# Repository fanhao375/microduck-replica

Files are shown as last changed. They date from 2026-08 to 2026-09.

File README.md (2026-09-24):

# Microduck 复刻

**简体中文** · [English](README.en.md)

> 对 [Pollen Robotics Microduck](https://pollen-robotics.com/microduck/) 的第三方复刻研究。
> 从官方公开的 MJCF 仿真模型反推出**装配图、爆炸图和可直接导入 CAD 的装配体**。

Microduck 是一只 25cm 高、737g 的双足机器鸭，15 个 Dynamixel XL330 舵机（14 个受策略控制），用强化学习走路。
它的**软件开源（Apache-2.0）**。硬件是**部分开源**：

- ✅ **RPI Robot HAT 板完整开源** —— 见 [`pollen-robotics/elec_RPI_Robot_HAT`](https://github.com/pollen-robotics/elec_RPI_Robot_HAT)（Apache-2.0）：
  KiCad 9 工程、Gerber、BOM、贴片坐标、STEP 一应俱全。这块板**不需要自己画**。
- ❌ **`imu_to_dxl` 板未开源** —— 全网无公开工程，本仓库的逆向是目前唯一公开重建。
- ❌ **机械件无可编辑 CAD**、无 BOM、无装配文档。

> 📌 **勘误（2026-09-03）**：本文档此前写作「硬件不开源、没有 PCB 原理图」，**这是错的**。
> 当时只检索了 `pollen-robotics/microduck` 主仓，未翻查该组织下以 `elec_` 开头的硬件仓库。

但官方在 `microduck_rl` 里发布了完整的 **MJCF 仿真模型 + 47 个 STL 网格**。
MJCF 里包含了完整的运动学树：每个零件挂在谁身上、相对位置精确到 0.1mm、
绕哪根轴转、行程多少、质量和惯量张量。

**这些信息足以还原出装配关系。** 本仓库就是把它还原出来的结果。

---

## 两条路线，选一条走

本仓库同时覆盖两种舵机。**机械、电路、软件三层都有差别**，动手前先定：

| | 原版 · Dynamixel XL330 | 飞特 · HD-1910 |
|---|---|---|
| **舵机** | XL330-M288-T ×15 | HD-1910-C001 ×15 —— 便宜一半、力矩 2.5 倍 |
| **电压** | 额定 6 V，实跑 6.6–8.2 V，**超压 37%** | 额定 4–8.4 V，在额定内；但满电 8.4 V 顶格 |
| **打印件** | [`print/`](print/) 上游 STL 直接打 | **8 个配合件要改**（HD-1910 舵盘凸、XL330 凹）—— [拓竹一键打印](https://makerworld.com.cn/zh/models/2963569-microduck#profileId-3478428) / [3mf](https://github.com/fanhao375/microduck-replica-cad/tree/master/打印) |
| **可编辑图纸** | [图纸仓 v1.1](https://github.com/fanhao375/microduck-replica-cad/releases/tag/v1.1) | [图纸仓 v2.0](https://github.com/fanhao375/microduck-replica-cad/releases/tag/v2.0)，文件带 `-FT` 后缀 |
| **电路** | 官方 HAT + [`imu_to_dxl`](hardware/imu_to_dxl/) | 同左；舵机连接器 2.0 mm（官方 2.5），`imu_to_dxl` 板上 J4/J5 是 2.0 |
| **软件** | 官方运行时直接跑 | 总线协议不同，要换协议模块 —— [适配架构分析](software/飞特适配架构.md)；策略要按 HD-1910 重训 —— [训练前数据清单](docs/HD-1910训练前数据清单.md) |
| **状态** | 纸上分析 + 首批打印件 | **整机装出实物**（2026-09-13），**15 颗上总线、能站起来坐下**（2026-09-18），零位和站姿还在调 |

选型论证在 [执行器选型](docs/执行器选型.md)。本仓库主线走飞特；原版资料同样齐全，两条都能复刻。

---

## 交流群

有人在做同样的事，凑了个微信群一起讨论复刻进度、踩过的坑、元件采购。

下面是**鸭子复刻群 9**的二维码（微信群满 200 人后无法扫码加入）。

<div align="center">
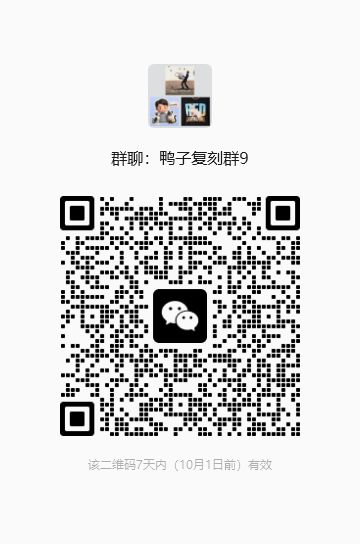
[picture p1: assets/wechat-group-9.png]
鸭子复刻群 9 微信二维码
  
  <br>
  <sub><b>鸭子复刻群 9 · 二维码有效期到 2026-10-01</b>（微信群码 7 天自动失效）<br>
  过期了请开个 <a href="https://github.com/fanhao375/microduck-replica/issues">issue</a> 说一声，我会换上新的</sub>
</div>

## 最近更新

**IMU 姿态接入调试台**：[`tools/servo-web/`](tools/servo-web/) 可选接入 J-Link，在同一个 3D 鸭子上显示舵机关节角与 IMU 躯干姿态。配套固件在 [`hardware/imu_to_dxl/firmware/`](hardware/imu_to_dxl/firmware/)，**0.2.0 已改成飞特协议**（ID 200、地址 56、15 字节），电脑上验收全过，等整机上真总线实测；没有 J-Link 也能用 ST-Link / DAPLink（`--imu-swd`）或直接走舵机总线（`--imu-bus`）看姿态。

<table>
<tr>
<td width="50%" valign="top">

### 🔌 电气 · 15 颗舵机整机上电，站起来了（2026-09-18）

<p align="center"><a href="assets/首次上电-2026-09-18.mp4">第一次上电：从缩着站起来（点开看 30 秒视频）</a></p>

装好的鸭子第一次接总线：URT-2 走 USB、7.4 V 进 V1，**15 颗 HD-1910 全部在线，0 超时 0 校验错**，一次同步读 15 颗 4.8 ms。
用仓库里新写的[网页调试台](tools/servo-web/)拖滑块、存姿态、跑序列，3D 模型跟着真机动，重心投影实时显示在不在脚底范围。
上面这段是它从缩着**自己站起来**再坐下。**飞特路线的软件第一步走通了**，硬件方案没问题。

`imu_to_dxl` 板首板已到：3.3 V 正常，J4/J5 接口封装要改，固件还没写 —— [设计说明与评审记录](hardware/imu_to_dxl/)。

**[网页调试台](tools/servo-web/)**　·　
**[调试记录](调试记录.md)**（零位、方向、站姿的坑）　·　
[踩坑记录](踩坑记录.md#工具)（URT-2 先插 USB 再上电）　·　
[飞特适配架构](software/飞特适配架构.md)

</td>
<td width="50%" valign="top">

### 🔨 机械 · 飞特 HD-1910 版装出来了

<a href="构建日志.md">飞特 HD-1910 版装机实物</a>

**15 颗飞特 HD-1910 全部配好 ID、装进机身。** 这不是官方的 XL330 —— 便宜一半、力矩大 2.5 倍、
电压额定匹配，是[执行器选型](docs/执行器选型.md)里论证的那条路，现在有实物了。

**HD-1910 的舵盘是凸的，XL330 是凹的**，跟舵盘配合的 8 个件同事全改了、重新打印。
可编辑的 SolidWorks 图纸也出了飞特版（`-FT` 后缀），改了什么、为什么，
在图纸仓里写清楚了。

**[构建日志](构建日志.md)**　·
**[飞特版 SolidWorks 图纸](https://github.com/fanhao375/microduck-replica-cad)**　·
**[拓竹一键打印](https://makerworld.com.cn/zh/models/2963569-microduck#profileId-3478428)**　·
**[BOM 清单 · 带采购链接](https://github.com/fanhao375/microduck-replica-cad#装配-bom)**　·
[调试记录](调试记录.md)　·
[打印件清单](print/)
</td>
</tr>
<tr>
<td width="50%" valign="top">

### 💻 软件 · 网页调试台，串口直连 15 颗舵机

<p align="center"><a href="tools/servo-web/">网页调试台：滑块、3D 鸭子、重心投影</a></p>

浏览器拖滑块让舵机动，3D 鸭子跟着转，重心投影实时算在不在脚底范围。
存姿态、跑序列、一键校准零位、导出全部寄存器、时序测试，装机和台架验收都用它。

后端不依赖飞特 SDK，[`feetech.py`](tools/servo-web/feetech.py) 按 2026 版协议手册直接收发包，一百多行。
配套一个**协议级舵机模拟器**，不接硬件就能把校准、改 ID、写寄存器跑一遍自检。

接官方运行时的 `FeetechIo`（`RobotIo` 接缝，rustypot 协议 v1）已经写完、跟上了官方 0.14.1，等零位校准做完上板 —— 代码在 fork 的 **[`feetech` 分支](https://github.com/fanhao375/microduck/tree/feetech)**。

**[网页调试台](tools/servo-web/)**　·
**[飞特适配架构](software/飞特适配架构.md)**　·
**[FeetechIo 代码](https://github.com/fanhao375/microduck/tree/feetech)**　·　
[飞特官方资料](docs/飞特资料/)（协议、内存表）

</td>
<td width="50%" valign="top">

### 🧠 算法 · 接入公开的 1910 M6 参数

采用 **[LuwuDynamics/xgoduck_rl](https://github.com/LuwuDynamics/xgoduck_rl) 公开的 1910 BAM M6 动力学参数**，
作为飞特版的仿真训练基线。感谢 LuwuDynamics 的分享；这份参数不是我们自行辨识的结果。
出处、固定版本、原文件校验值和 Apache-2.0 许可见[参数来源说明](docs/HD-1910-M6参数来源.md)。

完整训练工程已放入本仓库 **[`software/training/`](software/training/)**，一次克隆即可取得
代码、参数和仿真模型；[运行说明与初始化修复解释](software/training/docs/hd1910-baseline.md)给出具体命令。
训练沿用 [Pollen Robotics/microduck_rl](https://github.com/pollen-robotics/microduck_rl) 和
[Rhoban/BAM](https://github.com/Rhoban/bam)。已通过接入测试和短训练检查，尚无本机实测通过的走路策略。
实机测试仍需完成**零位、关节方向、IMU 和主控接入**，并核对本机质量惯量与舵机响应。

**[HD-1910 训练前数据清单](docs/HD-1910训练前数据清单.md)**　·
[执行器选型](docs/执行器选型.md)

</td>
</tr>
</table>

---

## 🔨 实物进度

> 本仓库反复强调「仿真 STL 不是可打印工程件」。**构建日志就是在验证这句话。**
> 结论会如实记录，无论正反。

**→ [构建日志](构建日志.md)**（机械）　·　**[调试记录](调试记录.md)**（电气与软件）　·　**[踩坑记录](踩坑记录.md)**

---

## 🦆 鸭友贡献

这个仓库不是一个人写的。合并进来的代码、实测验证过的结论，都记在这儿。

| 谁 | 贡献了什么 |
|---|---|
| [@yoyojacky](https://github.com/yoyojacky) | **Rust 版飞特舵机测试工具**（[PR #27](https://github.com/fanhao375/microduck-replica/pull/27)，已合并）。自己实现的最小 STS/SCS 协议（帧打包、校验和、ping、读写寄存器、状态解析），命令行可以扫描总线（带进度条）、读状态、转到指定位置、单颗测试和批量测试，输出位置偏差、峰值电流、峰值负载、电压温度并判定 PASS/FAIL。台架验收一条命令出汇总表 → [`tools/sts3215Servo_testtool/`](tools/sts3215Servo_testtool/) |
| [@Abo1ish](https://github.com/Abo1ish) | **IMU 小板固件 + 调试台姿态显示**（[PR #32](https://github.com/fanhao375/microduck-replica/pull/32)，已合并）。给官方没开源的那块 imu_to_dxl 写了 STM32G031 固件底子，在实板上验证过，带主机端测试和一份写清楚边界的 [`VALIDATION.md`](hardware/imu_to_dxl/firmware/VALIDATION.md) → [`hardware/imu_to_dxl/firmware/`](hardware/imu_to_dxl/firmware/)；再用 J-Link 把 IMU 姿态实时读出来并进了网页调试台，3D 鸭子的躯干跟着真板子转（`--imu-jlink`，没板子也能用 `--imu-demo` 先看效果）→ [`tools/servo-web/`](tools/servo-web/) |
| 微信群的鸭友 | **Radxa Zero 3W V1.12J 的启动方案**。这批板子（WiFi 换成 AIC8800DS2）光换瑞莎引导还是起不来，他实测出设备树也得换成瑞莎 B1 的：**B1 引导 + B1 DTB + Armbian 6.1.115 内核 + Trixie 系统**，跑通了 → 写进了[踩坑记录](踩坑记录.md#软件)和[镜像使用说明](tools/radxa/镜像使用说明.md#6-如果你的板子不是这一批) |

### 鸭友的项目

有些鸭友是自己单独开仓库做的，不在这个仓库里，但跟鸭子直接相关、做得好的，放这儿推一下：

| 项目 | 作者 | 做什么的 |
|---|---|---|
| [microduck-color-studio](https://github.com/LathamZ/microduck-color-studio)（[在线试用](https://lathamz.github.io/microduck-color-studio/)） | [@LathamZ](https://github.com/LathamZ) | **鸭子的 3D 配色工作室，打印前先在网页里把颜色定好。** 70 个零件逐件上色，选材质（PLA / 哑光 / PETG / 金属 / 碳纤 / TPU）和灯光看效果；填上自己手里有哪些耗材，它按库存推荐配色（只用已有 / 补一色 / 丙烯点缀）。还能导入自己的 3MF（比如飞特版），导出**带颜色的多盘 3MF** 和按件拆好的 STL，拓竹 P1S / A1 mini / H2D 有预设。中英文界面，手机上也能看 |
| [MICDUCK_FTHD1901_REBUILD](https://github.com/fengj4780-sudo/MICDUCK_FTHD1901_REBUILD) | [@fengj4780-sudo](https://github.com/fengj4780-sudo) | **飞特版结构改进 + 可选 CNC 加强件。** 在我们的[可编辑 SolidWorks 图纸](https://github.com/fanhao375/microduck-replica-cad)基础上接着改：适配飞特舵机（他仓库里写作 HD1901，零件文件用的是 HD-1910-C001），加强了薄弱件，修了装配干涉和几个破损的模型。腿部 **5 个零件可以换成 CNC 件**让受力更合理（还在打样测试，他估算 5 件含运费约 45 元）；不做 CNC 直接打印也行，强度也比原版好。附一键打印的 3MF（拓竹 H2D、0.4 mm、5 盘）和改好的 SolidWorks 图纸 |

做了跟鸭子有关的项目（工具、教程、改装、策略……），开 issue 贴个链接，我们加进来。

想加进来：直接开 [issue](https://github.com/fanhao375/microduck-replica/issues) 或提 PR。
硬件、固件、算法、文档、实测数据都算 —— **实测数据尤其欢迎**，这个仓库的规矩是结论如实记录，无论正反。

---

## 装配爆炸图

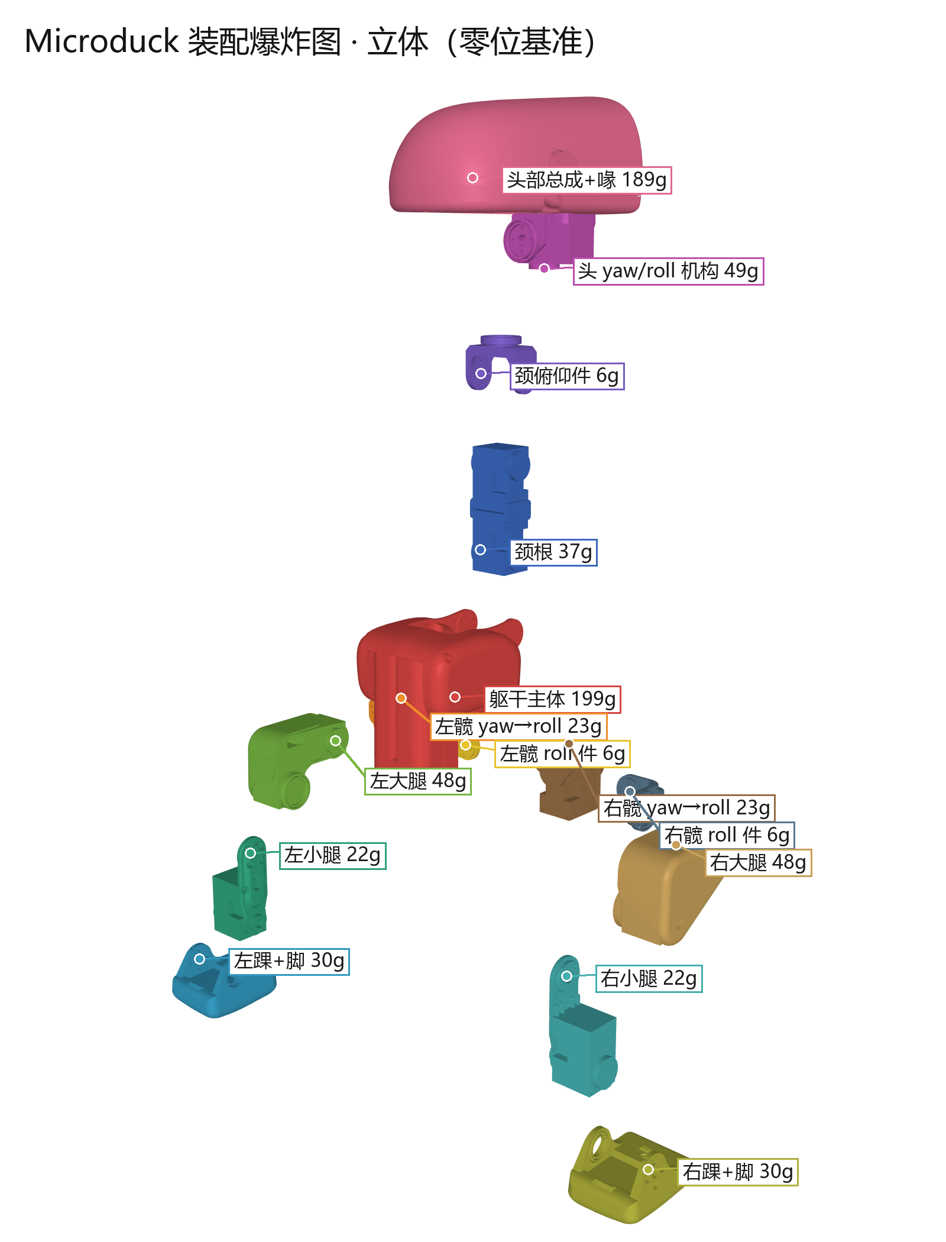
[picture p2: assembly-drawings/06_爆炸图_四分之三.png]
爆炸图


`assembly-drawings/` 下共 7 张：

| 文件 | 内容 |
|---|---|
| `01_正面` `02_侧面` `03_背面` `04_四分之三` | 装配完成态，原色 |
| **`05_爆炸图_侧面`** | 15 个部件沿运动链炸开，标注名称与质量 |
| **`06_爆炸图_四分之三`** | 立体视角，可看清左右腿镜像关系 |
| `07_分色对照_装配态` | 与爆炸图同配色的装配完成态，对照用 |

## 装配结构

```
躯干主体 199g
├─ 左髋 yaw→roll 23g → 左髋 roll 6g → 左大腿 48g → 左小腿 22g → 左踝+脚 30g
├─ 颈根 37g → 颈俯仰件 6g → 头 yaw/roll 机构 49g → 头部总成+喙 189g
└─ 右髋 yaw→roll 23g → 右髋 roll 6g → 右大腿 48g → 右小腿 22g → 右踝+脚 30g

整机 737.2g   外形 144 × 141 × 264 mm
```

躯干和头几乎一样重（199g vs 189g）——**头部占整机四分之一，重心很高**，
这解释了为什么它的行走策略难训。

## 关节参数

每条腿 5 个自由度，头颈 4 个 —— **14 个受控**。
整机实际装 **15 个 Dynamixel XL330**：第 15 个驱动喙/下颚，走被动连杆，不进动作空间。

| 关节 | 行程 |
|---|---|
| `hip_yaw` | -25° ~ +30° |
| `hip_roll` | ±22° |
| `hip_pitch` / `knee` / `ankle` / `head_pitch` | ±90° |
| `neck_pitch` | -90° ~ +60° |
| `head_yaw` | ±170° |
| `head_roll` | ±25° |

## 📋 物料清单（BOM）

**要买什么、买几个** —— [`BOM.md`](BOM.md)

整机 15 个舵机、14 个轴承、约 325 件紧固件、2 块要打样的电路板，数量取自上游 MJCF 的
引用计数（38 种网格 / 75 个实例），不是估的。含每块板的器件清单与立创编号。

> ⚠️ 里面有两条会让人买错的更正：**电池是 NP-F550 不是 F970**、**XL330 被超压运行**。

## 3D 打印件

整机全部 STL 单件，按「要打印 / 买现成的」分好类，中英双语命名 —— [`print/`](print/)

| 目录 | 数量 |
|---|---|
| 🖨️ [**拓竹 MakerWorld · microduck**](https://makerworld.com.cn/zh/models/2963569-microduck#profileId-3478428) | **不想看图直接打** —— 一键切片，Bambu 打印机直接开 |
| [`print/打印件/`](print/打印件/) | **30 种 / 41 件**结构件 |
| [`print/标准件-无需打印/`](print/标准件-无需打印/) | **9 个**外购件模型（对位用） |

> 上游的 XL330 台架测试夹具在另一个目录，本来就不属于机器人。打印建议与数量表见 [`print/README.md`](print/README.md)，采购见 [机械采购清单](docs/机械采购清单.md)。

## CAD 装配体

`cad/` 下是**已应用世界变换**的 STL —— 直接导入 CAD 就是装好的样子，
不用自己摆位置（上游那 47 个 STL 都是零件自身坐标系的，直接导入会全部堆在原点）。

- `00_Microduck_整机装配体.stl` —— 整机单文件，796792 三角面
- `01` ~ `15` —— 按刚体分组的 15 个部件，文件名即部件名
- `零件对照表.json` —— 每个部件由哪些上游源网格组成

单位 **毫米**。可直接用 FreeCAD / Fusion 360 / SolidWorks / Blender / 各类切片软件打开。

### 📐 要可编辑的参数模型？在另一个仓库

本仓库的 `cad/` 与 `print/` 都是**网格（STL）**—— 能打印、能看、能测量，但**改不动**。

**[fanhao375/microduck-replica-cad](https://github.com/fanhao375/microduck-replica-cad)**
是配套的三维图纸仓库，放的是**可编辑的 SolidWorks 源文件**（📦 **压缩包在那个仓库的 Releases 页，不在文件列表里**）：
16 个装配体 + 40 个零件，外加一份 **21 页的装配安装说明书**（含每个组件的步骤、配图与注意事项）。

> 那套图纸由 **[机械行者Robo](https://github.com/fanhao375/microduck-replica-cad#图纸作者机械行者Robo)**
> 建模并编写说明书 —— 想改尺寸、改壁厚、重新出工程图的，从那边拿源文件。

---

## 从运行时反推出的电控方案

<div align="center">
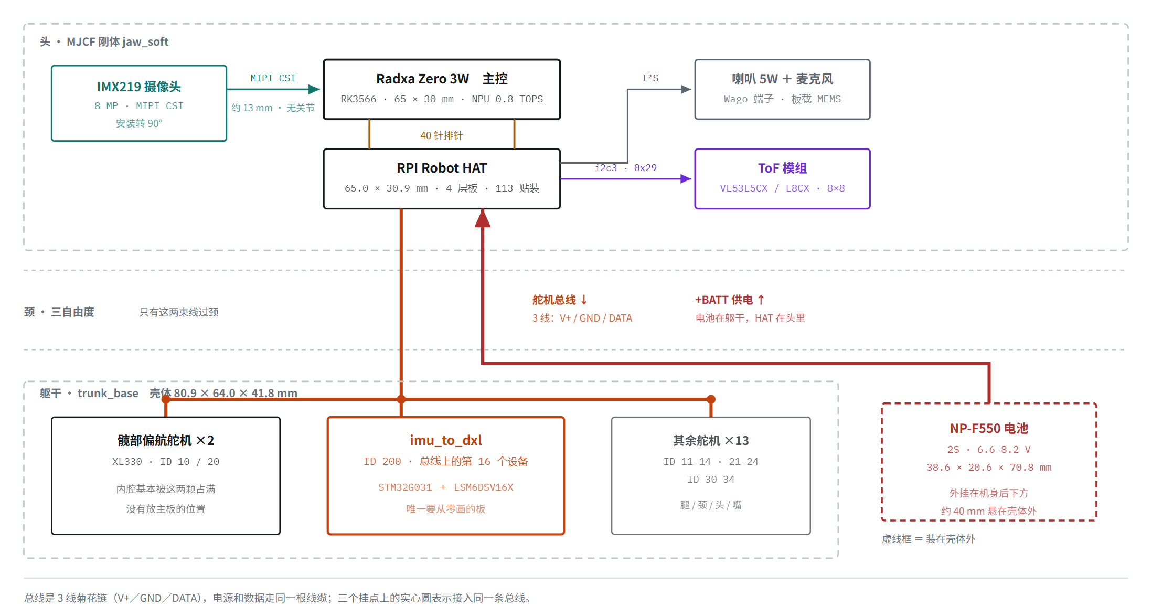
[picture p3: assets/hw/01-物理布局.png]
Microduck 电控总览：板子都装在哪
  
  <br>
  <sub><b>五个模块的物理布局</b> —— 灰色虚线框是物理区域，实线框是模块，红色虚线框表示装在壳体<b>外面</b>。<br>
  <b>橙色</b>是舵机总线（自上而下），<b>红色</b>是电池供电（自下而上）。<br>
  最容易搞错的一条：<b>主控、HAT、摄像头三者都在头里</b>，摄像头距主控板中心约 13 mm 且中间没有关节 ——<br>
  所以 MIPI 排线不穿过脖子，真正过颈的是舵机总线和供电线。<br>
  <a href="docs/硬件入门.md">完整图集与讲解 →</a>　·　<a href="assets/hw/Microduck硬件图集.pdf">下载 PDF 图集（7 张，A3）</a></sub>
</div>

**一条 1 Mbps 的 TTL 串行总线搞定一切。**

```
                Radxa Zero 3W (RK3566) · Armbian
                  ├── UART2  1 Mbps TTL 单线半双工 ── 15× XL330 + imu_to_dxl (ID 200)
                  ├── I2C3   400 kHz (pin 3/5) ────── AIC3104@0x18 · ToF@0x29 · BMI088（未用）
                  ├── I2S3   12.288 MHz ───────────── 音频
                  ├── MIPI CSI ────────────────────── IMX219（I2C@0x10，转 90°）
                  ├── 蓝牙 ────────────────────────── 手柄 / 手机 App
                  ├── Wi-Fi ───────────────────────── WebRTC
                  └── USB-C ───────────────────────── 供电 + maskrom
```

| | |
|---|---|
| **主控** | **Radxa Zero 3W** —— 市售模块，**不是定制载板** |
| SoC | RK3566，四核 Cortex-A55，Mali-G52，0.8 TOPS NPU。官方公布 1 GB / 32 GB eMMC；复刻建议 2G/16G，见 [电控采购清单](docs/电控采购清单.md) |
| **舵机总线** | **单线半双工 TTL** —— **不是** RS-232，**也不是** RS-485。Dynamixel Protocol V2 @ 1 Mbps，走 `/dev/ttyS2` |
| **自制板 1** | **`imu_to_dxl` v2** —— 一颗会说 Dynamixel 的 LSM6DSV16X：总线 ID 200、寄存器 124，12 字节块在**同一次** `sync_read` 里和舵机一起读回 |
| **自制板 2** | **RPI Robot HAT** —— TLV320AIC3104 @ 0x18、一颗休眠的 BMI088、接 ToF 的 Stemma 座。**官方已开源**（[`elec_RPI_Robot_HAT`](https://github.com/pollen-robotics/elec_RPI_Robot_HAT)） |
| 电池 | 索尼 NP-F550，2S 锂电。**没有电量计，也没有 ADC** —— 电池电压是**读舵机上报的自身供电电压**得来的 |
| 传感器 | LSM6DSV16X IMU · VL53L5CX/L8CX 8×8 ToF · IMX219（树莓派 Camera v2） |

`imu_to_dxl` 是整套设计里最漂亮的一手：**IMU 不走 I²C**，而是把自己伪装成一个 Dynamixel 从机，
于是姿态数据和关节状态在同一次总线事务里回来 —— 不需要第二条总线，主机也不用跑姿态融合
（LSM6DSV16X 的片上 SFLP 块直接输出游戏旋转四元数，还自己估计陀螺零偏）。

**完整细节：** [硬件方案逆向](docs/硬件方案逆向.md) · [硬件规格速查](docs/硬件规格速查.md)

---

## 可行性：能造出来吗

**整机可复刻，卡点在成本不在技术。** 现状：

| 项目 | 状态 |
|---|---|
| 零件几何 | ✅ 47 个 STL |
| 装配关系 | ✅ 精确到 0.1mm，已出图 |
| 关节轴线 / 行程 | ✅ 14 个全有 |
| 质量 / 惯量 | ✅ 15 个刚体全有 |
| 舵机型号 | ✅ Dynamixel XL330 ×15 → [docs/执行器选型.md](docs/执行器选型.md) |
| 轴承 | ✅ Ø22×16×4 与 Ø15×10×3 |
| **HAT 板** | ✅ **官方 KiCad + Gerber + BOM 已开源**，直接打样 → [`elec_RPI_Robot_HAT`](https://github.com/pollen-robotics/elec_RPI_Robot_HAT) |
| **`imu_to_dxl` 板** | ⚠️ 未开源，需自绘；协议与寄存器布局已完整还原 → [docs/硬件方案逆向.md](docs/硬件方案逆向.md) |
| 主控 | ✅ **Radxa Zero 3W，市售模块**（此前误判为定制载板） |
| **紧固件清单** | ✅ 已从 STL 孔位反推 → [docs/紧固件反推.md](docs/紧固件反推.md) |
| 电池 / 传感器 | ✅ **NP-F550** 2S、IMX219、VL53L8CX、LSM6DSV16X |
| **走线方案** | ❌ 无 |
| **控制软件** | ✅ 主控用同款 Radxa Zero 3W 即可直接跑（Apache-2.0）；换主控才需移植 |
| **官方策略 ONNX** | ✅ 硬件保持同款即可直接用（9 个）；改动本体或电控才需重训 |

⚠️ **仿真 STL ≠ 可打印工程件。** 仿真只关心外形与惯量，不保证配合公差、
螺纹孔、热熔螺母座和走线空间。直接打印大概率装不起来，需要自行补充工程细节。

💰 **自己造大概率比买贵，但差多少全看渠道。** 15 个 XL330 在 ROBOTIS 国际站约 **$359**、
美国站 **$412**、欧洲含税 **€603–629** —— 也就是从「略低于整机售价」到「远超」都有可能。
加上主控、电池、两块板打样和打印耗材必然更贵。完整核价见 [BOM.md](BOM.md)。

## 现实路径

放弃 100% 复刻（`imu_to_dxl` 板与可编辑机械 CAD 未开源），改成**机械照抄 + 电控自建**：

| | 方案 |
|---|---|
| 机械 | 用本仓库的 STL 与装配图，几何完全照抄 |
| 舵机 | XL330 × 15，市售件照买 |
| 主控 | **Radxa Zero 3W**，市售模块，与官方同款 |
| IMU 板 | 自己画 `imu_to_dxl`：LSM6DSV16X + MCU + 半双工收发器，协议已还原 |
| HAT 板 | **官方 Gerber 直接打样**（4 层板）。不要录音可整块省略，但**半双工方向电路要另配转接板**，见 [电控采购清单](docs/电控采购清单.md#六两块-pcb) |
| 软件 | 主控同款则官方 Rust 运行时可直接跑（Apache-2.0） |
| 策略 | 官方 9 个 ONNX 可用；改硬件后用 [microduck_rl](https://github.com/pollen-robotics/microduck_rl) 重训 |

**结论已从「机械可抄、电控是硬墙」修正为「整机可复刻」** ——
主控是市售模块，自制板的功能和协议已从源码完整还原。
详见 [docs/硬件方案逆向.md](docs/硬件方案逆向.md)。

---

## 三个必踩的坑

1. **Armbian 默认在 UART2 上跑登录控制台。** `serial-getty@ttyS2` 占着串口，
   必须 `systemctl mask` 掉。Pollen 是用 `fuser -v /dev/ttyS2` 查出来的。
2. **i2c3 和 FUSB302 抢引脚。** 用排针 pin 3/5 的硬件 I²C，代价是**失去 USB-C PD 协商**
   （普通 5V 充电仍然可用）。
3. **NPU 出厂是关的。** Armbian 默认禁用，要跑 RKNN 模型得刷 overlay 并重启。

---

## 生态导航

Microduck 的东西散在 GitHub 多个组织和 HuggingFace 三种资源里，**官方硬件仓库尤其容易漏**。
[`docs/生态导航.md`](docs/生态导航.md) 把官方仓库、模拟器、策略模型、数据集、社区项目
逐个标注了「是什么、能拿来干嘛」。

## 深入文档

| 文档 | 内容 |
|---|---|
| [紧固件反推](docs/紧固件反推.md)（[English](docs/fastener-reconstruction.en.md)） | 从 47 个 STL 扫描孔特征，反推出 M2 螺丝系统与采购量 |
| [执行器选型](docs/执行器选型.md)（[English](docs/actuator-selection.en.md)） | XL330 参数、BAM M6 配置、5 组标定 PD、回差建模；**为什么不能换闭环步进、换 STS3215 会怎样**（737g vs 2107g 实测对照）、**同级别舵机横向对比**（含宇树 S288 深度评估） |
| [**踩坑记录**](踩坑记录.md) | **上手前扫一遍** —— 买东西 / 打板 / 飞线 / 软件 / 工具，每条三句：现象、原因、怎么办 |
| [**调试记录**](调试记录.md) | **拿到货一步一步做** —— 舵机配 ID 改哪些参数（含 ID 对照表）、怎么供电，后面按日期记过程 |
| [**HD-1910 训练前数据清单**](docs/HD-1910训练前数据清单.md) | **给算法重训用的** —— 几何、质量惯量、关节标定、舵机规格、IMU 安装，仓库有的全填了并标出处，台架实测项列了怎么测 |
| [**不打 HAT**](docs/不打HAT.md) | **HAT 打样太贵？** ¥70 的降压模块 + 半双工转接板飞线替代，一步一步接，哪步会烧东西 |
| [**硬件入门**](docs/硬件入门.md) | **一块板一块板讲清楚** —— 五个模块各自干嘛、一个 tick 里信号怎么流、走飞特路线哪些会变，末尾附「复刻前必做的五件核对」 |
| [**硬件规格速查**](docs/硬件规格速查.md) | **一页纸规格表** —— 系统框图、芯片型号、总线参数、复刻清单、必踩的坑 |
| [硬件方案逆向](docs/硬件方案逆向.md) | 完整推导过程与证据出处（[English](docs/hardware-teardown.en.md)） |
| [**电控采购清单**](docs/电控采购清单.md) | **淘宝实链** —— 主控 / 摄像头 / ToF / 电源 / 两块 PCB / 线材与调试板，含选型推算与避坑（2026-09-04 快照） |
| [**机械采购清单**](docs/机械采购清单.md) | **淘宝实链** —— 轴承 / M2 紧固件 / 热熔螺母与压头 / 螺纹胶 / 耗材 |
| [社区动态](docs/社区动态.md) | X / GitHub 情报，含外部验证、噪音与风险提示 |

结论速览：**整机是 M2 螺丝系统**（Ø2.2 过孔 ×77 + Ø4.4 沉头孔 ×28 + Ø1.6 攻丝底孔 ×20），
结构件过孔约 146 个；轴承 Ø22×16×4 与 Ø15×10×3。

---

## 重现

```bash
# 1. 为下列装配图生成脚本拉取上游（训练工程已在 software/training/，无需此步骤）
bash scripts/fetch_upstream.sh

# 2. 重新生成装配图
python scripts/render_assembly.py upstream/microduck_rl assembly-drawings

# 3. 重新导出 CAD 装配体
python scripts/export_assembly_stl.py upstream/microduck_rl cad

# 4. 重新扫描孔特征
python scripts/analyze_holes.py upstream/microduck_rl/src/mjlab_microduck/robot/microduck/assets
```

依赖：`mujoco` `numpy` `pillow` `scipy`。渲染需要可用的 OpenGL 上下文。

---

## 许可证

- `scripts/` —— Apache-2.0
- `assembly-drawings/` `cad/` —— **CC BY-SA-NC 4.0**（上游 3D 模型为 CC BY-SA-NC，
  依 ShareAlike 条款衍生作品须沿用同协议，**不得商用**）

详见 [NOTICE.md](NOTICE.md)。本项目与 Pollen Robotics 无隶属关系，未获其背书。

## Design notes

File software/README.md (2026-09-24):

# software · 软件适配

官方运行时 [`pollen-robotics/microduck`](https://github.com/pollen-robotics/microduck) 是照 Dynamixel XL330 写的，本仓库主线用飞特 HD-1910，软件要改。这个目录放**训练工程、分析和方案**；Rust 运行时适配代码仍在下方所列的 fork 分支里。

## HD1910 仿真训练

**[`training/`](training/)** 包含完整 Python 训练工程：模型、LuwuDynamics 的 1910 M6 参数、
HD1910 任务配置、飞特控制器初始化适配、依赖锁文件和测试。克隆本仓库即可取得，
不需要再下载 `microduck_rl` 分支。

[快速开始](training/README.md) · [运行说明与初始化问题解释](training/docs/hd1910-baseline.md) ·
[来源和许可证](training/UPSTREAM.md)。当前是仿真接入基线，尚未完成本机实测步态训练。

## IMU 裸板调试

STM32G031 + LSM6DSV16X 固件与硬件资料放在 [`hardware/imu_to_dxl/firmware/`](../hardware/imu_to_dxl/firmware/)。姿态显示并入 [`tools/servo-web/`](../tools/servo-web/)：使用 `python server.py --port COM5 --imu-jlink imu-jlink.json`，同一个模型同时接收舵机关节角和 J-Link 的躯干姿态；只有裸板时可用 `--fake` 代替串口参数。

**范围：SWD 台架观察。** 附带固件仍是 Dynamixel Protocol 2.0 基线，尚未实现飞特地址 56、15 字节契约，不能据此宣布飞特 IMU 总线或整机验收通过。

## Rust 运行时代码在哪

> ### 👉 [`fanhao375/microduck` · `feetech` 分支](https://github.com/fanhao375/microduck/tree/feetech)
>
> 已跟上官方 **0.14.1**，三个 crate 的测试全过（duck-control 80 / robotd-params 151 / robotd 93）。**还没上过板**，等零位校准。

| 文件 | 行数 | 做了什么 |
|---|---|---|
| [`duck-control/src/bus_feetech.rs`](https://github.com/fanhao375/microduck/blob/feetech/duck-control/src/bus_feetech.rs) | 744（新） | **`FeetechIo` 主体**：每 tick 一次 `sync_read` 地址 56 长 15；位置换算带方向表；写目标带钳位；`set_gain` 只写 P（飞特没有 I/D 同构）；`reboot` 先关扭矩再 0x08；开机检查 END 字节序 / 应答级别 / 运行模式 / 波特率 / 相位；`imu_ready()` 恒 false。含 11 个单元测试 |
| [`duck-control/src/bus_select.rs`](https://github.com/fanhao375/microduck/blob/feetech/duck-control/src/bus_select.rs) | 149（新） | `AnyBus` 枚举，两种后端二选一（`Box<dyn RobotIo>` 编不过，原因见[架构文档](飞特适配架构.md) §3.1） |
| `robotd-params/` | +50 | `[bus] protocol = "dynamixel2" \| "feetech-sts"`、`[bus.feetech] p_scale / directions`，登记进参数表 |
| `robotd/src/main.rs` | +63 | `BusIo` 换成 `AnyBus`，开总线时带协议；参数不合法直接报错不重试 |
| `duck-control/src/model.rs` | +8 | HD-1910 出厂运行模式 4 的期望值 |
| `deploy/robotd.toml` | — | 两个新键，带注释 |

编译（需要 Rust）：

```bash
git clone -b feetech https://github.com/fanhao375/microduck.git
cd microduck && cargo test -p duck-control -p robotd-params -p robotd
```

**为什么放 fork 不放这个仓库**：`FeetechIo` 是官方 Rust 工作区里 `duck-control` 这个 crate 的一个文件，
用的是官方的 `RobotIo` trait、`Safety<T>` 泛型和参数系统 —— 单独拷出来编译不了。
放在 fork 分支上，官方更新时 `git rebase` 就能跟上（2026-09-20 跟了 55 个提交，零冲突），
将来也能直接向官方提 PR。官方是 Apache-2.0，改动留在 fork 里出处也清楚。

| 文件 | 内容 |
|---|---|
| [`飞特适配架构.md`](飞特适配架构.md) | 官方运行时现有架构（接缝在哪、每个 tick 干什么、开机序列）、两家舵机逐项差别、适配方案、**`imu_to_dxl` 小板固件架构（§4）**、台架验收、待查清单、构建部署 / 策略关系 / 失败模式、评审记录 |

小板固件的接口契约（15 字节块、时序、排队规则、验收）单独成文：[`hardware/imu_to_dxl/总线协议.md`](../hardware/imu_to_dxl/总线协议.md)，配套工具 [`tools/imu200/`](../tools/imu200/)（假小板 + 测试向量 + 真板子验收）。

板子怎么烧、怎么装官方运行时，在 [不打 HAT](../docs/不打HAT.md) 和 [`tools/radxa/`](../tools/radxa/)。

飞特协议和内存表的官方原文（2026 年版快照）在 [`docs/飞特资料/`](../docs/飞特资料/)。

动代码前先把舵机点通：[`tools/servo-web/`](../tools/servo-web/) 是接串口的网页调试台，拖滑块、看回读、导寄存器底账、3D 鸭子跟着动，架构文档台架清单 0–8 项都用它。

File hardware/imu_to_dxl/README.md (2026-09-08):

# imu_to_dxl 原理图 + PCB · 求评审

> ⚠️ **这是第三方复刻件，不是官方设计。**
> 官方从未公开这块板的原理图、Gerber 或外形（全网零命中，见
> [硬件方案逆向](../../docs/硬件方案逆向.md)）。本目录是根据 MJCF 模型、官方运行时源码
> 和已开源的 HAT 工程反推 + 自行选型的结果，**未经打样、未经实物验证**。
> 发现问题请开 [issue](https://github.com/fanhao375/microduck-replica/issues)。

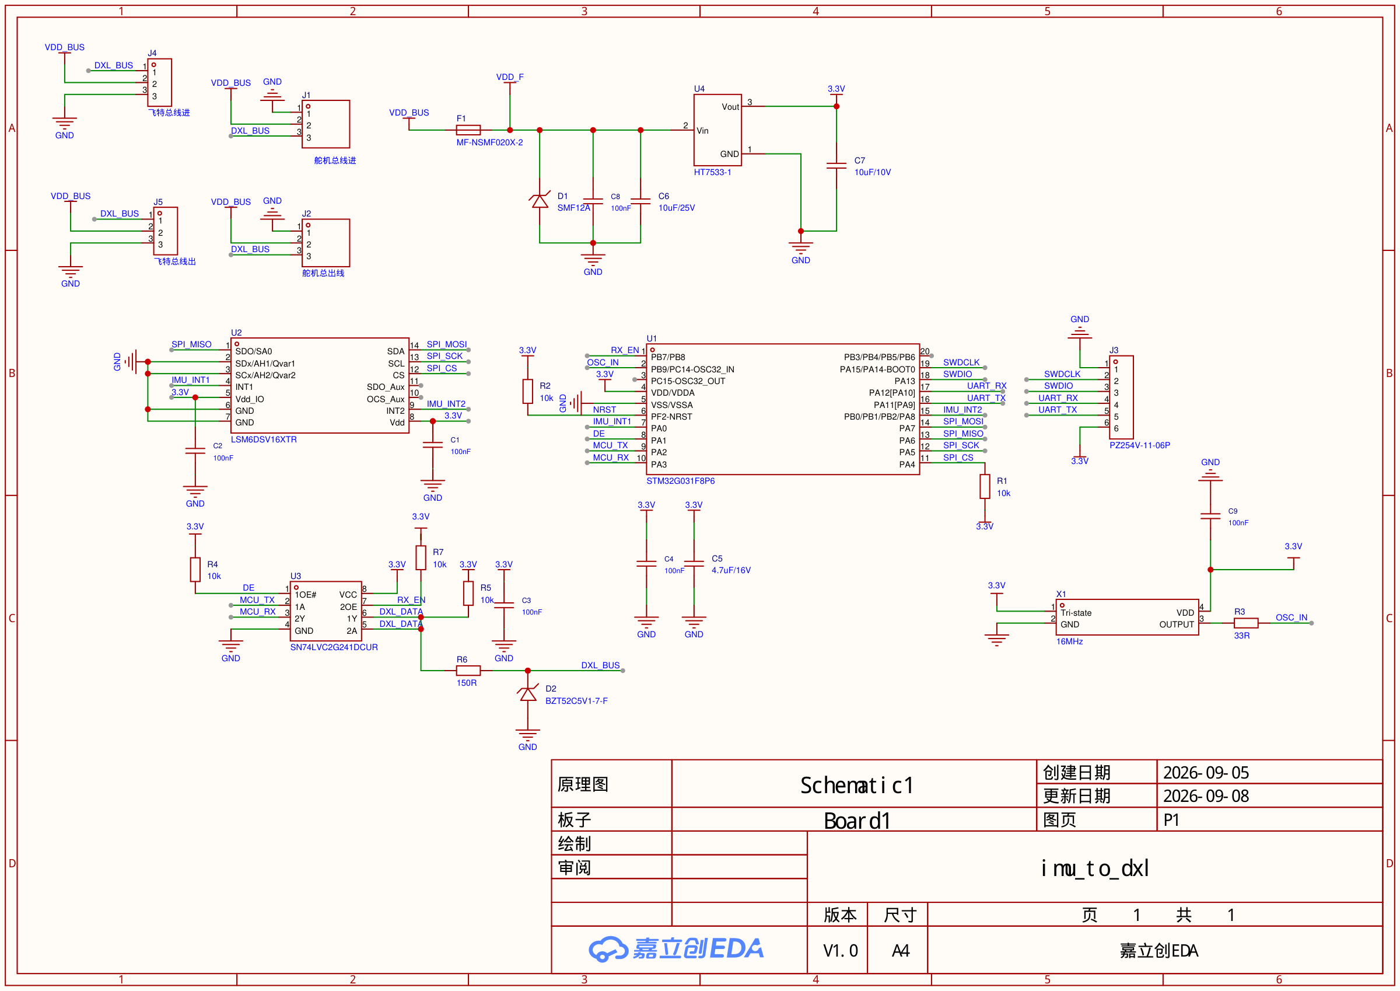
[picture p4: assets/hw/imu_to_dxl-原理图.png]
imu_to_dxl 原理图


| 文件 | 说明 |
|---|---|
| [`imu_to_dxl-原理图.pdf`](imu_to_dxl-原理图.pdf) | 矢量 PDF，放大看细节 |
| [`imu_to_dxl-接线表.md`](imu_to_dxl-接线表.md) | 逐网络列出每个引脚，可以直接对着核 |
| [`imu_to_dxl.eprj2`](imu_to_dxl.eprj2) | 嘉立创 EDA 专业版工程，可直接打开改 |
| [`../../BOM.md`](../../BOM.md) | 完整 BOM，含立创编号与每颗器件的选型理由 |

---

## 这块板干什么

官方 Microduck 的 15 个舵机挂在一条 Dynamixel 半双工总线上。这块小板
**作为第 16 个设备挂在同一条总线上**，对外表现成一个 Dynamixel 从机（ID 200），
主控用读寄存器的方式向它要姿态数据。

板上的 IMU 用的是 **LSM6DSV16X**，它片内有 **SFLP 硬件融合块**，
直接输出游戏旋转四元数 —— 姿态解算不占主控算力，也不占总线带宽。

```
主控（树莓派/泰山派）
      │  1 Mbps 半双工单线
      ├── 舵机 ×15
      └── imu_to_dxl（本板，ID 200）
             ├── LSM6DSV16X   SPI 四线 + 两路中断
             ├── STM32G031F8P6 收包 / 组包 / 读 IMU
             └── SN74LVC2G241 半双工收发缓冲
```

## 核心选型与理由

| 位号 | 器件 | 为什么选它 |
|---|---|---|
| **U1** | STM32G031F8P6 | ① USART 有**硬件 DE**（RS485 Driver Enable）—— 1 Mbps 下一个比特只有 1 µs，软件翻方向脚的抖动就在这个量级。对照：**STM32F401 手册全文没有 "Driver Enable"**，只能软件切<br>② 与 IMU 同厂，ST 的 `lsm6dsv16x-pid` 驱动和 SFLP 例程现成 |
| **U2** | LSM6DSV16XTR | 片内 SFLP 融合，直接出四元数 |
| **U3** | SN74LVC2G241DCUR | 双缓冲做单线半双工。通道 1 左进右出、通道 2 右进左出，正好对着走线。3.3 V 供电时**输入耐 5.5 V**，扛得住舵机 5 V 的信号 |
| **U4** | HT7533-1 | **耐压 30 V** —— 前两道保护都失效时它自己还活着 |
| **F1** | PPTC MF-NSMF020X-2 | **24 V / 200 mA 保持**。本板故障时先断自己，不拖垮整条舵机总线 |
| **D1** | TVS SMF12A | 截止 12 V > 满电 8.4 V，钳位 19.9 V < C6 的 25 V 耐压 |
| **C6** | 10 µF / **25 V** | 挂在 8.4 V 母线上。MLCC 有直流偏压衰减，6.3 V/10 V 的余量不够 |
| **C5** | 4.7 µF | 与 C4 的 100 nF 组成 ST 要求的组合 —— **DS12992 Rev 3, Figure 13** 对 `VDD/VDDA` 明确标注 `1 × 100 nF + 1 × 4.7 μF` |

## 几个可能有争议的决定

### 1. `2OE` 接常高，发送时会听到自己的回显

`U3.1 (1OE#)` 接 DE 控制发送缓冲，`U3.7 (2OE)` **直接接 3.3 V，接收缓冲常开**。

- 代价：发送时 MCU 会在 RX 上收到自己发的字节，固件按发送长度丢弃
- 好处：PA3 永远有人驱动，**不会悬空**

备选是 `2OE` 也接 DE（发送时关掉接收），但那样发送期间 RX 浮空，
重新使能时可能产生假起始位。我选了前者，**欢迎反驳**。

### 2. 没有晶振，只留了焊盘

TSSOP-20 封装**没有引出 `OSC_OUT`**（DS12992 Rev 3, Table 12：2 脚 `PC14` 的附加功能有
`OSC_IN`，3 脚 `PC15` 只有 `OSC32_OUT`），所以**无源晶振根本接不了**。

HSI16 精度（Table 41）：出厂 −0.75%/+0.5%，0–85 °C 温漂 ±1% → 最坏约 **−1.85%/+1.55%**。
1 Mbps 异步 UART 典型容差 ±3%，够用但余量不多。

板上留了 **X1（16 MHz 有源晶振，HSE 旁路）+ C9 + R3** 三个焊盘，**默认不贴（DNP）**。
另外固件可以用定时器输入捕获测主机来的比特周期，反调 `HSITRIM`（步进 0.2–0.4%/档），
误差能压到 0.3% 以内，不花钱。

### 3. J1 / J2 保留两个，靠铜皮解决过流

J1 和 J2 三根线一一并联。**本板若在链条中间，下游全部舵机电流都流过本板的连接器和铜箔。**

飞特 HD-1910-C001 官方参数：额定 **500 mA** / 堵转 **1.8 A**。

但这个约束**不是本板独有的** —— 舵机之间本来就是菊花链，它们自己的连接器承受同样的电流。
HAT 有 **4 个舵机接口**，15 个舵机分在 4 条支路上，每条最多 4 个，一条支路额定约 **2 A**，
在 3 A 以内。官方设计能接受，本板用同样的座子不会更差。

**所以保留两个座子**：想挂末端就不装 J2，想串中间就装上，灵活性几乎零成本。
PCB 上把 `VDD_BUS` 与 `GND` 从 J1 到 J2 走**大铜皮**（≥ 2 mm 或直接铺铜）即可。

> 曾有评审意见建议「只留一个 3P 座子」。那在本板确定是叶子节点时成立，
> 但**如果它是链条第一个节点**（HAT 出来先进本板、再出去给舵机），就必须两个。
> 官方拓扑无从确认，保留两个更稳。

### 4. 协议靠软件自动识别，没做跳线/拨码

飞特与 Dynamixel 的物理层完全相同（半双工单线 / 1 Mbps / 3 线 / GND-VCC-DATA），
差别只在包格式：

| | 包头 | 后续 | 校验 |
|---|---|---|---|
| Dynamixel V2 | `FF FF` | **`FD 00`** | CRC-16 |
| 飞特 SCS | `FF FF` | `ID` + `LENGTH` | `~(ID+LEN+INST+参数)` |

飞特官方协议文档写明 **Length = 参数个数 N + 2**，所以最小为 2、**永远不会是 0**；
ID 范围 0–253。→ `FF FF FD 00` 只可能是 V2，**判别无歧义**。

固件收前 3 包投票锁定协议，之后按锁定的收发；连续 100 包解析失败则解锁重判。
比拨码开关可靠（会走路的机器人里，拨码触点是振动失效点）。

### 5. J3 用 6P，把串口 printf 也引出来

`1=GND 2=SWDCLK 3=SWDIO 4=UART_TX 5=UART_RX 6=+3V3`，前 4 脚顺序不变，
**原来的 4 针 SWD 排线插 1–4 仍可用**。

UART 来自 U1 脚 16/17（`PA11[PA9]` / `PA12[PA10]`），经 `SYSCFG_CFGR1` 重映射成
`USART1_TX/RX`。

**不上 USB**：G031 没有 USB 外设（手册 Development support 只写 "serial wire debug (SWD)"），
加 USB 要多一颗 CH340/CP2102，45 × 22 mm 板上不划算。
调试走 SWD + RTT（`probe-rs` 支持在 CMSIS-DAP 上跑 RTT，不停 CPU）。

> Cortex-M0+ **没有 SWO/ITM**，别指望 SWO printf。

---

## 板框与安装孔

| 项 | 值 |
|---|---|
| 板框 | **45 × 22 mm**，2 层板 |
| 四角 | **R2 圆角** |
| 安装孔 | **2 × M2 非金属化孔 φ2.2 mm**，走对角 |
| 孔位（板左下角为原点） | MH1 (2.667, 2.413)、MH2 (42.672, 19.685) mm |
| 孔距 | X 向 40.00 mm ／ Y 向 17.27 mm ／ 对角 43.57 mm |
| 孔到板边 | MH1 **1.31 mm** ／ MH2 **1.22 mm**（嘉立创要求 ≥0.4 mm） |

两孔中点 (22.67, 11.05) 与板心 (22.50, 11.00) 相差 0.17 mm，**转 180° 装基本还能对上**（偏差 0.34 mm）。

> ⚠️ **孔位在 2026-09-08 改过。** 原设计是 MH1 (5.5, 3.5) / MH2 (39.5, 18.5)、X 向 34 mm，
> 刻意对齐原版 `banana_pcb_locker` 打印件的两个定位耳间距。
> **加 `J4`/`J5` 时 MH2 的让位圈正好卡住右边那条唯一能放插件的空白带**，
> 于是把两个孔都往角上挪，X 向变成 40 mm。
> **代价是不再与原锁扣通用 —— 机械侧同步改压条。**
> 反正逆向文档里「锁扣压的就是 `imu_to_dxl`」本来也只是推断
> （见 [硬件方案逆向](../../docs/硬件方案逆向.md)），硬约束只有「IMU 刚性固连在 `trunk_base` 上」这一条。

板框文件：`imu_to_dxl-板框-45x22-R2.dxf`（单位 mm，8 段闭合：4 直边 + 4 段 90° 圆弧）。

> **为什么单独给 DXF**：这版立创EDA专业版的图元接口只接受铜层，
> 往板框层（layer 11）建线/弧一律报「参数不正确」，改层、改文档源都被挡，
> 所以板框走 DXF 导入（`文件 → 导入 → DXF`，目标层选**板框层**，单位 mm，原点对齐 0,0）。
> 两个 M2 孔不在 DXF 里 —— 它们已经作为真实的 NPTH 焊盘建在 PCB 上了。

## PCB：布局与布线

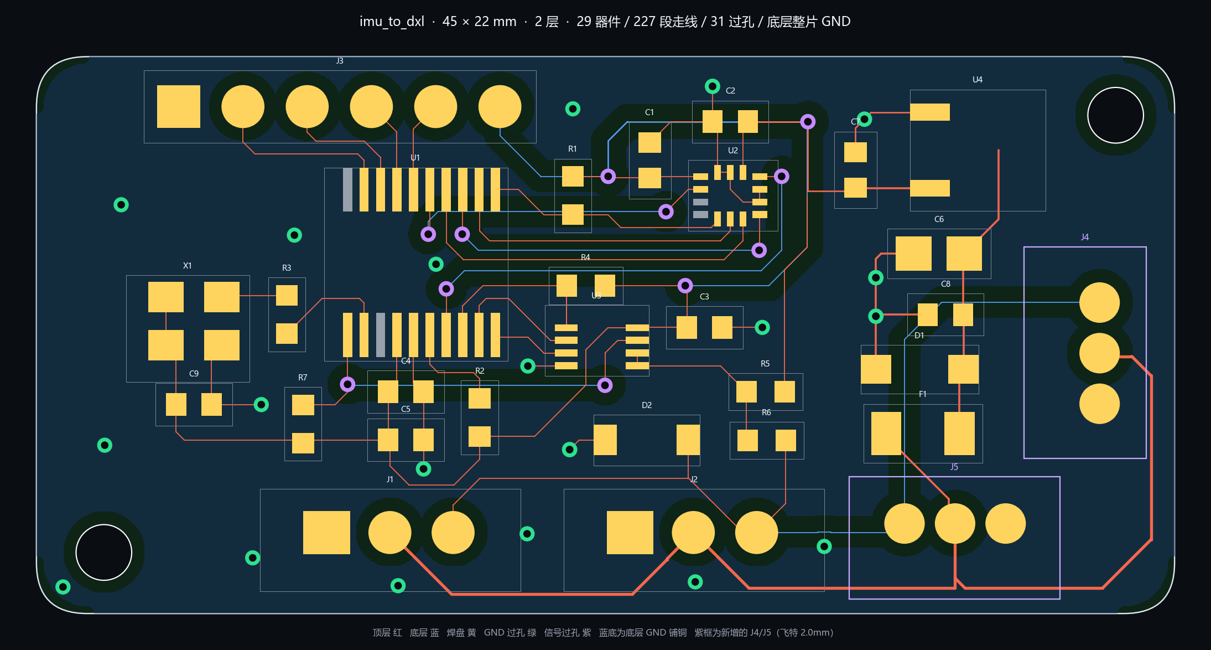
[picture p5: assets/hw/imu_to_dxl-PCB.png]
imu_to_dxl PCB 顶层装配图


*布线图，由工程实测数据渲染（顶层红 / 底层蓝 / 焊盘黄 / GND 过孔绿 / 信号过孔紫，蓝底为底层 GND 铺铜，紫框为 `J4`/`J5`）。*
*状态 2026-09-08：29 器件 · 227 段走线 · 31 过孔 · 172 泪滴，含 `R7`、`J4`、`J5`，`X1`/`R3`/`C9` 已改为实贴。*
*本目录的 `.eprj2` / PCB PDF / 原理图 PDF / STEP 与 `assets/` 下两张图，**全部已更新到 2026-09-08 的最终版**。*

**45 × 22 mm，2 层板，1 oz 铜**，四角 R2 圆角，两个对角 M2 非金属化孔。
贴片件全在正面；3 个插件连接器分两条边：`J1` `J2`（舵机总线）在下边，
`J3`（SWD + 串口）在上边。

### 分区

| 区 | 内容 | 为什么 |
|---|---|---|
| 下边 | `J1` `J2` 总线连接器（JST EH 2.5 mm） | 线束从躯干走线，就近出线 |
| 右下 | **`J5` 飞特总线出**（2.0 mm） | 与 `J1`/`J2` 同侧，四个座子的 `VDD_BUS` 直通铜皮连成一条 |
| 右边缘 | **`J4` 飞特总线进**（2.0 mm） | 全板唯一放得下插件的空白带；为它让路才把 MH2 挪走的 |
| 右侧 | `F1` → `D1` → `C6`/`C8` → `U4` → `C7` | 电源链一条路走到底，跟数字区隔开 |
| 中部 | `U3` 缓冲 + `D2` 钳位 + `R6` 串阻 | 夹在 MCU 和总线连接器之间，收发路径最短 |
| 中上 | `U1` 主控、`U2` IMU 及各自去耦 | |
| 左侧 | `X1` / `R3` / `C9` 时钟位 | 已改为实贴，放在边角不占好位置 |
| 上边 | `J3` 调试排针 | 插拔方向朝外 |

### 布线

| 项 | 值 |
|---|---|
| 元件 | **29 个**（含 09-07 新增的 `R7`、09-08 新增的 `J4`/`J5`） |
| 走线 | **227 段**（顶层 197 / 底层 30） |
| 线宽 | 信号 0.25 mm 为主；**总线直通 0.76 mm** |
| 过孔 | **31 个，φ0.6 / 孔 0.3 mm** |
| 泪滴 | 172 个 |
| 铺铜 | **底层整片 GND**，顶层不铺 |

底层 30 段走线，**地平面基本完整**——这是给 SPI 和 1 Mbps 半双工总线留的回流路径。
顶层的 GND 焊盘各自就近打过孔下到地平面。

### 复查结果 · 2026-09-08

除立创自带 DRC 外，另用脚本按**真实焊盘形状**（圆形 / 跑道形 / 矩形）重新栅格化，
独立复核了一遍：

| 检查项 | 结果 |
|---|---|
| 立创 DRC | **0 违规** |
| **连接器脚序** | **四个全对**：`J1`/`J2` = `GND`/`VDD_BUS`/`DXL_BUS`；`J4`/`J5` = `DXL_BUS`/`VDD_BUS`/`GND`（**反序**，见下方脚序一节） |
| 网络连通性 | **23 个网络全部连通**（栅格连通域 + 过孔/插件孔跨层，含底层铺铜） |
| 异网最小间距 | **0.152 mm ＝ 5.98 mil**（精确几何，非栅格）。嘉立创双面板下限 0.127 mm，余量 20% |
| 铜到板边 | 最小 **0.37 mm** |
| 孔到孔（孔壁间） | 最小 **0.751 mm**，要求 ≥0.4 mm |
| 孔到板边 | MH1 **1.31 mm** / MH2 **1.22 mm** |
| M2 让位 | MH1 让位圈 2.5 mm 内只有一个 **GND** 过孔（1.81 mm）—— 螺钉压到地还是地，无害；MH2 最近 4.59 mm |
| 过孔规格 | φ0.6 / 孔 0.3 mm，符合嘉立创双面板下限 |
| 去耦距离 | `U1.4`→`C4` 2.27、`U2.8`→`C1` 2.00、`U2.5`→`C2` 2.01、`U3.8`→`C3` 1.96、`X1.1`→`C9` 2.39 mm，均 <2.4 mm；`U4.3`→`C7` 2.94 mm。⚠️ `U4.2` LDO 输入侧的 100nF `C8` 为 **6.64 mm**（偏松，但管瞬态的 10µF `C6` 在 4.29 mm，且 LDO 是线性的无开关） |

**载流核算**：四个座子之间的 `VDD_BUS` 直通链
`J1.2 → J2.2 → J5.2 → J4.2` **全程 0.76 mm**，1 oz 铜下 ΔT=10K 约 2.0 A、ΔT=30K 约 3.2 A。
JST EH 单触点额定 3 A，**走线与连接器基本同一量级**，加宽并不能抬高整条链路的上限。
另有 4.7 mm 的 0.51 mm 段在 `J1.2 → F1.1` 这条**只喂本板自己**的支路上，
前面是 200 mA 保持的 PPTC，够用。

> **2026-09-08 抓到并修掉一处**：布 `DXL_BUS` 去 `J4`/`J5` 时，有一个 φ0.3 过孔
> 落在了 `J2.3` 的 φ1.0 插件孔正上方（孔心距 0.001 mm）。立创 DRC 报
> `Hole to Hole (DXL_BUS): J2_3 ↔ e75` —— 钻孔是机械工序，同网络也不允许重叠。
> `J2.3` 本身是贯穿孔、顶底早已连通，该过孔纯属冗余，删除后连通性不变、DRC 归零。

**仍未验证**：**没有打样，没有实物**。以上全部是几何与规则层面的核对，
不能替代实测。

### 待办

- 下单前跑一次**器件标准化**（原理图 DRC 报过「元件属性与供应商编号不匹配」）
- 丝印复核：位号是否压焊盘、`U1` 一脚 / `D1` `D2` 阴极 / `J1` 一脚标记是否齐全
- **连接器高度**：`J1`/`J2`/`J3` 是 JST EH / 2.54 排针直插，本体约 **8 mm**。若躯干内腔
  确实只有 6.65 mm，需换卧式 `S3B-EH-A`，封装与 BOM 都要跟着改 —— 用导出的 STEP 在
  装配体里比一下即可定论。
  **`J4`/`J5` 反而不用担心**：`B3B-PH-K-S` 本体约 **6.0 mm**，塞得进 6.65 mm 的内腔
- **板端座子型号待确认**：飞特规格书只写了线端是 `AMP2.0-3P`，**板端型号没给**。
  本板暂用 `B3B-PH-K-S`（JST PH，2.0 mm 立式）。焊盘阵是三孔 2.0 mm 间距，
  与其它 2.0 mm 系列通用，**将来换系列只改封装、不动焊盘、不重布线**
- **下单前重导生产文件** —— 器件从 27 变 29，立创那边的 Gerber / BOM / 贴片坐标都要重传

## 想请你重点看这几处

1. **`2OE` 常开这个取舍**（上面第 1 条）—— 回显 vs RX 悬空，哪个更糟
2. **J1/J2 过流与铜皮宽度**（第 3 条）—— 2 mm 够不够
3. **HSI16 跑 1 Mbps 的余量**（第 2 条）—— 有实测经验的说一声
4. **三道过压防线够不够** —— 8.4 V 母线 + 舵机反电动势
5. **连接器**：见下方「⚠️ 飞特脚序按型号不同，而且是反的」。`J4`/`J5` 两个 2.0 mm 座子
   已在原理图与 PCB 上落位（2026-09-08），但**板端座子的确切系列还没拿实物比过**
   —— 飞特规格书只写了线端 `AMP2.0-3P`，板端型号待厂家确认

## ⚠️ 飞特脚序按型号不同，而且是反的

**这是本板最容易致命的一处，两份厂家规格书各自都没错 —— 是两个型号真的相反。**

| | 连接器 | 脚 1 | 脚 2 | 脚 3 |
|---|---|---|---|---|
| **`HD-1910-C001`**（本仓库选用） | **`AMP2.0-3P`**（2.0 mm） | **Signal/TTL** | Vcc | **GND** |
| `HL-2915-C002`（另一型号，勿照抄） | `AMP-3` | **GND** | Vcc | **Signal/TTL** |
| 本板 `J1`/`J2`（JST EH 2.5 mm，同官方 HAT） | `B3B-EH-A` | GND | VDD_BUS | DXL_BUS |
| 本板 `J4`/`J5`（2.0 mm，对口飞特） | `B3B-PH-K-S` | **DXL_BUS** | VDD_BUS | **GND** |

四个座子的脚序已从 PCB 网表反读复核过，全部落对（2026-09-08）。
**两种间距插不进对方（2.0 vs 2.5 mm），物理上杜绝了插错，只剩「画错」这一种可能。**

出处：飞特《HD-1910-C001 串型规格书》**A/0，2026-09-07** 第 3/7 页 6-7 项；
飞特《HL-2915-C002 串型规格书》A/0，2026-02-27 第 4/8 页 6-7 项。
两份都是厂家发给客户确认的规格书，**本仓库按惯例不转载 PDF**，需要请向飞特索取。

> 本仓库此前只记了 `HL-2915` 那一行、却推荐 `HD-1910` 作为替代型号，**是个坑**，
> 2026-09-08 按 A/0 新规格书更正。
>
> ⚠️ **`HL-2915-C002` 是 9–14 V（典型 12 V）舵机，挂不上本方案的 2S 母线（6.6–8.2 V）**
> —— 它 9 V 才开始工作。当初拿它当「飞特接口惯例」的样本是权宜之计，别照着选型。
>
> ⚠️ **间距也对不上**：`AMP2.0` 是 2.0 mm，`JST EH` 是 2.5 mm，**插不进对方**。
> 好在这一点反而是保险 —— 物理上杜绝了插错，只剩「画错」这一种可能。

## 已确认 / 未验证

**已确认（一手资料）**

- **HD-1910-C001** 接口 `1=Signal/TTL · 2=Vcc · 3=GND`，连接器 `AMP2.0-3P`，线长 15±0.5 cm
  —— 飞特《HD-1910-C001 串型规格书》A/0 (2026-09-07) 第 3/7 页 6-7 项
- HD-1910-C001 走 **TTL 三针总线**，**4–8.4 V**，堵转 9/12/15 kg·cm @4.8/6/7.4 V，
  额定电流 **500/690/900 mA**，堵转电流 **1.2/1.6/2.0 A**，静态 20 mA，12 bit 磁编码，
  减速比 1/320 —— 同上规格书第 2/7、3/7 页
- **电机自带三道电子保护**（同上第 4/7 页 7-11）：
  **过流**（>0.5 A 持续 2 s 关输出，阈值与时长可自定义，**出厂默认关闭**）·
  **过压**（>10 V 或 <4 V 保护，范围可自定义，**出厂默认关闭**）·
  **过热**（>80 ℃ 关扭矩输出，**出厂默认开启**）。
  **装机前应把前两条打开** —— 异常检测在电机里做，主机不必轮询
- 反馈六项齐全：输入电压 / 负载 / 工作电流 / 工作速度 / 工作温度 / 位置（同上 7-10）。
  官方运行时确实在用：`present_current` 每 tick 随位置一起读，电压+温度约每秒一次，
  且**电压是整机唯一的电池计量手段**（`duck-control/src/{bus,model}.rs`）
- 出厂默认运行模式是**模式 4「纯位置 PD（Sim2Real）」**，正对强化学习落地（同上 7-12）
- 包格式、`Length = N+2`、校验算法、同步读 `0x82` —— 飞特官方《舵机SCS通信协议》
- 包格式、`Length = N+2`、校验算法、同步读 `0x82` —— 飞特官方《舵机SCS通信协议》
- STM32G031 无 HSE 引脚、HSI16 精度、`100 nF + 4.7 µF` 去耦要求 —— ST DS12992 Rev 3
- 原理图连通性 —— 已用脚本逐网络核对，无悬空脚、无短路、无重名网络

**未验证**

- **整块板没打样过**，没有实物
- 板框 45 × 22 mm 与 M2 孔 X 向 34 mm 间距是从打印件 `banana_pcb_locker` 反推的，非官方尺寸
- MCU 型号是本仓库的选型建议，**不是逆向所得** —— 官方那块板用什么 MCU 无从还原

---

## 评审记录

### 2026-09-07 · 三条布局/选型建议（都不采纳，理由记下来）

评审人看了图纸提了三条：阻容换 0402、IMU 放板心、LDO 远离 IMU。逐条量了数据，
**结论是维持现状**，但每条的理由值得记下来 —— 尤其第二、三条其实指向同一件事。

**① 阻容换 0402 —— 不换，理由不在「能不能手焊」**

对方补充说「别折腾自己焊接，团一下上立创贴片省心」。这个建议本身对，但换不换 0402
的判据不在这儿：本目录 2026-09-06 那条记录第一句就写了「**理由不是 0402 手焊不了**」
—— 板上有 LGA-14 的 LSM6DSV16X（底部焊盘 3×2.5 mm），本来就必须上热风。

真正的理由是**调试期返修**：`R6` 串阻要从 150 Ω 试到 33 Ω、上拉可能要摘、去耦可能要补。
**第一版没验证过的板子必然要改几次**，这一点不因为找立创贴片而改变 —— 贴片厂只负责
第一次，改还是得自己动烙铁。

代价那边：16 个阻容换 0402 省 **12.5 mm²，占板面积的 1.3%**，而这块板**只用了 36%
的面积**，根本不缺地方。0402 的 10k/100nF 在立创同样是基础库，省料费这条对两边都成立、
不构成理由。

**② IMU 放板心 · ③ LDO 远离 IMU —— 方向都对，但量级不同**

先量数：

```
板心 (22.5, 11.0) = 两个 M2 孔的中点（当初就是这么设计的）
U2 (IMU)  离板心 7.47 mm，离两螺钉连线 3.00 mm
U3 (缓冲) 离板心 0.41 mm      ← 最刚的位置被逻辑芯片占了
U2 ↔ U4 (LDO) 中心距 6.37 mm
```

**热的量级**：板上总电流约 5–10 mA（G031 约 3 mA + LSM6DSV16X 约 0.65 mA + 缓冲约 1 mA
+ 上拉），LDO 压降 8.4 − 3.3 = 5.1 V → **耗散约 51 mW**（满电最坏）。SOT-89 在小铜箔上
θJA 约 100–160 °C/W → 结温升 **5–7 °C**；隔 6.4 mm、中间一整片底层地铜散热，传到 IMU
处**温差约 1–3 °C**。LSM6DSV16X 陀螺零偏温漂约 0.05 °/s/°C → **约 0.1 °/s 偏置**。
走路时陀螺是几十 °/s 量级，且躯干里 15 个舵机吃安培级电流，热源比 51 mW 大两三个数量级。
**方向对，但不是主导项。**

**真正值得动的是第②条的另一面**：板心正好是两螺钉中点，是全板最不易形变的位置，
而现在坐在那儿的是不在乎位置的 `U3`。把 `U2`/`U3` 对调可一箭三雕 ——
IMU 离板心 7.47 → 0.4 mm，同时离 LDO 6.37 → **11.3 mm**（翻倍）。

**为什么这次仍不动**：板子已 DRC 0 违规、全部布通；对调意味着中间区域重排 + 重布
SPI×4、2 个中断、缓冲的 DE/TX/RX/DXL_DATA。按上面的量级估算，收益是"更稳妥"而非
"解决已知问题"。**留到打样后拿实测数据再决定** —— 若实测陀螺零偏随 LDO 负载明显漂移，
或振动噪声偏大，v2 一并改。

**一个更重要的提醒**：IMU 在**机器人里**的位置与朝向是训练模型定死的，比它在板上偏
7 mm 重要得多。那个由板子怎么装进躯干决定，已查证并记在
[`docs/硬件方案逆向.md`](../../docs/硬件方案逆向.md)：`trunk = [+raw_z, +raw_y, −raw_x]`，
绕 Y 轴 +90°。板上挪位置不影响这条。

### 2026-09-07 · 给 `2OE` 留一根控制线（R7 + RX_EN）

有人建议把「那个 EN 脚」预留一根线到 MCU。指的是 `U3.7 (2OE)` —— 接收缓冲的输出使能，
此前硬接 +3V3、接收常开。**已采纳。**

**改动**

| | |
|---|---|
| 断开 | `U3.7 (2OE)` 与 `+3V3` 的直连 |
| 新增 | **R7 = 10 kΩ 0603**（`C25804`，与 R1/R2/R4/R5 同一颗料，不新增料号） |
| 新网络 | **`RX_EN` = `U1.1 (PB7/PB8)` · `U3.7 (2OE)` · `R7.1`** |
| 保留 | `R7.2 → +3V3`（上拉） |

**为什么选 U1.1**：U1 空闲的是 1 脚 (PB7/PB8)、3 脚 (PC15)、20 脚 (PB3/PB4/PB5/PB6)。
3 脚是 PC15，在 G0 上与 LSE 共用、驱动能力受限；20 脚并了四个口最灵活，留着。
1 脚是普通 GPIO，且与 `DE`/`MCU_TX`/`MCU_RX` 同在下排，走同一条通道。

**默认行为完全不变** —— MCU 复位期间 PB7 高阻，R7 把 `2OE` 拉高，接收缓冲照常开着。
固件一行不写，跟改动前一模一样。这是**预留**：想消掉发送期间的回显时，把 PB7 配成推挽
输出拉低即可，同时打开 `MCU_RX` 脚的内部上拉，避免 `2Y` 高阻时 RX 浮空 ——
这正是此前否掉「`2OE` 接 DE」方案的那个顾虑，用独立 GPIO + 内部上拉就解决了。

**改后复查**：元件 26→27、网络 23→24，`RX_EN` = 3 个脚，`+3V3` 里 `U3.7` 已移出、
`R7.2` 顶上。立创 DRC **0 违规**，异网最小间距 **0.160 mm**（改前 0.153），
其余各项与 2026-09-07 首次复查一致。

**顺带更正**：本目录 `imu_to_dxl-接线表.md` 的「悬空脚」清单此前误列了 2、16、17 脚
（它们分别接 `OSC_IN`、`UART_TX`、`UART_RX`），已改。现在真正空闲的只有 3 脚与 20 脚。

### 2026-09-07 · 关于 U3 缓冲器的三个疑问（两条不采纳，一条改画法）

评审人查了 SN74LVC2G241 手册，对 U3 的接法提了三点。逐条核过 —— 网表是从
PCB 里现读的（PCB 网络由原理图导出，等价于原理图连接）：

```
U3 脚1  1OE#  → DE          脚5  2A   → DXL_DATA
U3 脚2  1A    → MCU_TX      脚6  1Y   → DXL_DATA
U3 脚3  2Y    → MCU_RX      脚7  2OE  → 3.3V
U3 脚4  GND   → GND         脚8  VCC  → 3.3V

DXL_DATA  4 脚：R5.2 R6.1 U3.5 U3.6     ← 不含 U3.7
DE        3 脚：R4.2 U1.8 U3.1
MCU_TX    2 脚：U1.9 U3.2
MCU_RX    2 脚：U1.10 U3.3
```

**① 「A 是输入、Y 是输出，所以脚3 该接 DXL_DATA、脚5 该接 MCU_RX」—— 前提对，结论反了**

手册原文没错：器件是两路独立使能的 1 位线路驱动器，数据方向恒为 **A → Y**。
但据此换线就错了：

- `MCU_RX` 是**要被缓冲器驱动的**网络（送进 MCU 的接收脚），必须落在**输出脚 Y**
  → 现在在脚3（2Y）✅
- `DXL_DATA` 是**要被读进来的**网络（总线上舵机发的），必须落在**输入脚 A**
  → 现在在脚5（2A）✅

按建议对调后，通道2 变成 `MCU_RX(2A) → DXL_DATA(2Y)`，等于从 MCU 的接收脚
往总线上发数据 —— RX 是输入脚不输出电平；而且 `1Y` 与 `2Y` 会同时驱动
`DXL_DATA`，两个驱动器直接对打。

现在的分工是标准半双工接法：**通道1 = 发**（`MCU_TX → 总线`，受 DE 控制），
**通道2 = 收**（`总线 → MCU_RX`，常开）。**不采纳。**

**② 「2OE 该串个上拉电阻，否则上拉太强」—— 电气上不成立，但画法要改**

`2OE` 是 CMOS 逻辑输入，输入电流量级 ±1 µA，直接接 VCC 是手册的标准用法。
串电阻没有任何收益，反而给高阻输入引入干扰耦合。

「上拉太强」这个担心，只有当该节点是**数据线**时才成立 —— 它不是：
`DXL_DATA` 网络只有 4 个脚（`R5.2` `R6.1` `U3.5` `U3.6`），**不含 `U3.7`**。
总线上拉是 `R5 = 10 kΩ`，值也合适。

**但这条提醒有价值**：会产生这个误解，是因为图上「2OE 的 3.3V 符号」正好压在
`DXL_DATA` 节点正上方，视觉上像连成一片。**已列为待改项：把该 3.3V 符号移开、
走线绕行**，消除歧义。属画法问题，不改电气连接。

**③ 「要默认导通的话，1OE# 应该接低电平」—— 默认不导通是有意的，不采纳**

`1OE#` 低有效，`R4` 把它**上拉到高**，意味着通道1（`MCU_TX → 总线`）
**默认关闭**。这是刻意的：

- 上电到固件跑起来之前，以及 MCU 死机 / 复位期间，本板**绝不能驱动总线**。
  总线是 15 个舵机共用的，一旦被钉住，整条链路通信全废。
- 若把 `1OE#` 常接低，`MCU_TX` 会一直往总线上灌，空闲高电平把总线拉死，
  舵机永远回不了包 —— 半双工不成立。

发送时由 MCU 把 `DE` 拉**低**。STM32 的 USART 硬件 Driver Enable 支持该极性，
`CR3.DEP = 1` 一个位搞定，外面不用加反相器。

> 这条与 2026-09-06 第 ① 条（社区反馈要求 DE 上拉）方向一致 ——
> 那次加 R4 正是为了保证「默认不驱动总线」，此处不能反过来。

**待办**：原理图上把 `U3.7` 的 3.3V 符号挪开，避免与 `DXL_DATA` 节点视觉相连。

### 2026-09-06 · 社区反馈（三条，两条已改）

**① DE 脚要上拉 —— 已改，这是漏项**

`U3.1 (1OE#)` 是低电平使能发送。上电与复位期间 MCU 的 **PA1 是高阻**，此脚浮空；
**若浮成低电平，发送缓冲就打开，本板会往总线上灌数据、与 15 个舵机全部撞车。**

已加 **R4 10 kΩ，DE → 3.3 V**。

此前在 `SPI_CS` 上加 R1 上拉正是同一个道理，**但没有推广到 DE**，属实是疏漏。

**② 两个 `DXL_DATA` 要连一起并上拉 —— 已改**

电气上原本就是同一个网络（`U3.5 2A` / `U3.6 1Y` / `J1.3` / `J2.3`），
但图上画成了两根各自带标签的短线，**看起来像没连**，是画法不够直观。已改为显式连接节点。

上拉这条也对：总线空闲无人驱动时，`2A` 这个 CMOS 输入浮空会有穿透电流，
UART 也可能把噪声当起始位 —— 本板应当自己定义空闲电平，不该依赖主机。
已加 **R5 10 kΩ，DXL_DATA → 3.3 V**。

**③ 只留一个 3P 连接器 —— 未采纳，理由见上面第 3 条**

该建议在本板确定为叶子节点时成立；但若本板是链条第一个节点则必须两个座子，
而官方拓扑无从确认。保留两个，靠铜皮宽度解决过流。

改完复核：`DE` 由 2 脚变 3 脚，`DXL_DATA` 由 4 脚变 5 脚，
全图无悬空脚、无短路、无重名网络。

### 2026-09-06 · 对照官方 HAT 复审（补两处保护）

把 [`pollen-robotics/elec_RPI_Robot_HAT`](https://github.com/pollen-robotics/elec_RPI_Robot_HAT)
的 `dynamixel.kicad_sch` 逐器件读了一遍，和本板对比。

**HAT 的 TTL 半双工电路**

```
                        ┌── R31 10k ── +3V3
   IO_15 (RX) ◄── U6 ───┘                    ┌── R32 10k ── +3V3
              (1G125, OE# 低有效)             │
                        ▲                     ▼
   IO_14 (TX) ──┬── U7 ──────────────────────► ● ── R33 150R ──┬── TH1 100R ── J13.3 / J14.3
                │  (1G126, OE 高有效)                       D4 5V1
                └── R27 10k ── Q1 (PNP) ── Dynamixel_dir        ⏚
```

**逐项对比**

| | 官方 HAT | 本板 | |
|---|---|---|---|
| 收发缓冲 | 1G125 + 1G126 两颗 | SN74LVC2G241 一颗 | 同逻辑 |
| 方向控制 | 从 TX 自动派生（Q1 + RC） | **USART2 硬件 DE** | 本板更好，见下 |
| 总线上拉 | R32 10 kΩ | R5 10 kΩ | 一致 |
| **数据线串阻** | R33 150 Ω + TH1 100 Ω | ❌ 无 → **已补 R6 150 Ω** | |
| **数据线钳位** | D4 5V1 | ❌ 无 → **已补 D2 5V1（同料号 `C151348`）** | |
| 电源保护 | 无（`+BATT` 直通连接器） | F1 PPTC + D1 TVS | 本板更好 |

**方向控制为什么本板更好**：HAT 从 TX 派生方向，靠 RC 时序回到接收态，
**释放早了会截断最后一个停止位**——这是 TX 派生方案的通病。
本板用 `USART2` 的硬件 DE，`DEAT`/`DEDT` 可按 1/16 比特精调，不存在这个问题。

**补完之后的数据线拓扑**（与 HAT 同构）：

```
U3.6 (1Y) ──┬─ DXL_DATA ─┬── R5 10k → 3.3V
U3.5 (2A) ──┘            │
                         └── R6 150Ω ──┬── DXL_BUS ── J1.3 / J2.3
                                       │
                                    D2 5V1
                                       ⏚
```

上拉留在**缓冲侧**（R5 在 R6 之前），与 HAT 的 R32 位置一致 ——
这样即使不插总线，`2A` 这个 CMOS 输入也有确定电平。

本板只串 150 Ω（HAT 是 250 Ω），因为 HAT 侧已经有 250 Ω，
总线上串太多会拖慢边沿。

复核：`DXL_DATA`（缓冲侧）4 脚、`DXL_BUS`（连接器侧）4 脚，
全图无悬空脚、无短路、无重名网络。

**顺带纠正本文档此前一处错误**：HAT 的 `TH1 100R 热敏`串在**数据线**上，
不是电源线上。`+BATT` 到 J13/J14 的第 2 脚是**粗线直通、无限流**。

### 2026-09-06 · 阻容封装统一改 0603

所有 0402 阻容改为 **0603**，D2 从 SOD-323 改为 **SOD-123**。

理由不是「0402 手焊不了」—— 板上有 **LGA-14 的 LSM6DSV16X**（底部焊盘 3 × 2.5 mm），
本来就必须上热风或回流，有那套工具 0402 也不难。

**真正的理由是调试期返修**：串阻要从 150 Ω 试到 33 Ω、某个上拉要摘掉、
去耦要补一颗 —— 这些在 0603 上拿烙铁几秒就能做，0402 得重新架热风。
一块没打样验证过的板子，第一版必然要改几次。

代价很小：11 个器件多占约 16 mm²，不到 45 × 22 mm 板面积的 2%。
而且 0603 这几个值**全在立创基础库**（10 kΩ `C25804` · 150 Ω `C22808` ·
33 Ω `C23140` · 100 nF `C14663`），比原来 0402 的扩展库还省上料费。

> C6（10 µF/25 V）保持 0805；C5（4.7 µF）、C7（10 µF）本来就是 0603。

换封装时同坐标同角度重放，实测**引脚坐标不变、连线一根没断**。
一个坑：`SOD-123` 的符号引脚顺序与 `SOD-323` 相反，换完 **D2 极性翻了**
（阴极跑到接地侧，正常工作会把总线钳到 0.7 V），已按引脚名核对并改正。
`create()` 的 `rotation` 参数在这个 API 里符号相反 —— 传 90 存进去是 270。

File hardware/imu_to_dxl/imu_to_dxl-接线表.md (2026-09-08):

# imu_to_dxl 接线表

> 手工连线用。器件位号与 `microduck-replica/BOM.md` 一致。
> 状态：方案稿，未经实物验证。

## 器件清单（含立创编号）

| 位号 | 器件 | 封装 | 立创编号 |
|---|---|---|---|
| U1 | STM32G031F8P6 | TSSOP-20 | C529334 |
| U2 | LSM6DSV16XTR | LGA-14 | C5267406 |
| U3 | SN74LVC2G241DCUR | VSSOP-8 | C10430 |
| U4 | HT7533-1（30V 输入，100mA） | SOT-89 | C14289 |
| F1 | PPTC MF-NSMF020X-2（24V / 200mA 保持） | 1206 | C210358 |
| D1 | TVS SMF12A | SOD-123FL | C2943870 |
| R1, R2, R4, R5 | 10kΩ | **0603** | C25804 |
| R6 | 150Ω | **0603** | C22808 |
| D2 | BZT52C5V1 5.1V 稳压管 | **SOD-123** | C151588 |
| C1–C4, C8 | 100nF 50V | **0603** | C14663 |
| C5 | 4.7µF / 16V X5R | 0603 | C19666 |
| C6 | 10µF / 25V X5R | 0805 | C15850 |
| C7 | 10µF / 10V | 0603 | C19702 |
| J1, J2 | B3B-EH-A（3P **2.5mm**，Dynamixel / 官方 HAT 线） | 直插 | C160259 |
| **J4, J5** | **B3B-PH-K-S（3P 2.0mm 立式，对口飞特 `AMP2.0-3P`）** | 直插 | 待定 |
| J3 | SWD+串口 6P 排针 PZ254V-11-06P | 直插 | C492405 |

## 网络表（23 个网络）

### VDD_BUS —— 舵机总线原压（2S 锂电 6.0–8.4V）
J1.2 · J2.2 · **J4.2** · **J5.2** · F1.1

> 四个座子的 `VDD_BUS` 走**直通铜皮**：`J1.2 → J2.2 → J5.2 → J4.2` 全程 0.76 mm。

### VDD_F —— 保险丝之后
F1.2 · D1 阴极 · C6.1 · C8.1 · U4.2 (Vin)

### +3V3
U4.3 (Vout) · C7.1 · U1.4 (VDD/VDDA) · C4.1 · C5.1 · R2.2 ·
U2.5 (Vdd_IO) · U2.8 (Vdd) · C1.1 · C2.1 · R1.2 ·
U3.8 (VCC) · C3.1 · J3.4 · **R7.2**

### GND
D1 阳极 · C6.2 · C8.2 · U4.1 (GND) · C7.2 ·
U1.5 (VSS/VSSA) · C4.2 · C5.2 ·
U2.2 (SDx) · U2.3 (SCx) · U2.6 (GND) · U2.7 (GND) · C1.2 · C2.2 ·
U3.4 (GND) · C3.2 · J1.1 · J2.1 · J3.1 · **J4.3** · **J5.3** · C9.2 · X1.2

### 复位
| 网络 | 连接点 |
|---|---|
| NRST | U1.6 (PF2-NRST) · R2.1 |

R2 另一端 (R2.2) 接 +3V3，构成 10k 上拉。

### 四个上拉电阻（R1/R2/R4/R5，另一端全部接 +3V3）

| 位号 | 拉住谁 | 为什么 |
|---|---|---|
| **R1** | `SPI_CS` | 上电与复位期间 PA4 高阻，CS 浮着可能被 IMU 误判成 I²C 模式，或把总线噪声当命令。**必须** |
| **R2** | `NRST` | 芯片内部已有 ~40 kΩ 弱上拉，外加 10 kΩ 提高抗干扰。加强项 |
| **R4** | `DE` | `1OE#` **低电平使能发送**。复位期间 PA1 高阻，此脚若浮成低电平，发送缓冲打开，本板会往总线上灌数据、与 15 个舵机撞车。**必须** |
| **R5** | `DXL_DATA` | 总线空闲无人驱动时，`2A` 这个 CMOS 输入浮空会有穿透电流，UART 也可能把噪声当起始位。本板自己定义空闲电平，不依赖主机 |

> R4 与 R5 是 2026-09-06 按社区评审意见补的。此前只在 CS 上做了上拉，
> **同样的道理没有推广到 DE，这是漏项**。

### IMU（SPI 四线 + 两路中断）
| 网络 | U1 (STM32) | U2 (LSM6DSV16X) | 其他 |
|---|---|---|---|
| SPI_CS | 11 · PA4 | 12 · CS | R1.1（R1.2 接 +3V3 上拉） |
| SPI_SCK  | 12 · PA5 | 13 · SCL | |
| SPI_MISO | 13 · PA6 | 1 · SDO/SA0 | |
| SPI_MOSI | 14 · PA7 | 14 · SDA | |
| IMU_INT1 | 7 · PA0  | 4 · INT1 | |
| IMU_INT2 | 15 · PB0/PA8 | 9 · INT2  | |

### 半双工总线（U3 = SN74LVC2G241 双缓冲）
| 网络 | 连接点 |
|---|---|
| MCU_TX | U1.9 (PA2 · USART2_TX) · U3.2 (1A) |
| MCU_RX | U1.10 (PA3 · USART2_RX) · U3.3 (2Y) |
| DE | U1.8 (PA1 · USART2_DE) · U3.1 (1OE#) · **R4.1** |
| DXL_DATA | U3.6 (1Y) · U3.5 (2A) · **R5.1** · **R6.1** —— 缓冲侧 |
| **DXL_BUS** | **R6.2** · **D2 阴极** · J1.3 · J2.3 · **J4.1** · **J5.1** —— 连接器侧 |
| **RX_EN** | **U1.1 (PB7/PB8)** · **U3.7 (2OE)** · **R7.1** —— 接收缓冲使能，2026-09-07 补 |

`U3.7 (2OE)` 原为直接接 +3V3，2026-09-07 改成 **`RX_EN` 网络**：经 **R7 10 kΩ 上拉到
+3V3**，同时引一根线到 **U1.1 (PB7/PB8)**。

**默认行为不变** —— MCU 复位期间 PB7 是高阻，R7 把 `2OE` 拉高，接收缓冲照常开着，
固件一行不写也跟改动前完全一样。这是**预留**：想关掉发送期间的回显时，把 PB7 配成
推挽输出拉低即可，同时打开 `MCU_RX` 脚的内部上拉，避免 `2Y` 高阻时 RX 浮空。

### 调试口 J3（6P，`PZ254V-11-06P` / `C492405`）

| 脚 | 网络 | 来源 |
|---|---|---|
| 1 | GND | |
| 2 | SWDCLK | U1.19 (PA14) |
| 3 | SWDIO | U1.18 (PA13) |
| 4 | **UART_TX** | **U1.16** `PA11[PA9]` → 重映射为 **PA9** = `USART1_TX` |
| 5 | **UART_RX** | **U1.17** `PA12[PA10]` → 重映射为 **PA10** = `USART1_RX` |
| 6 | +3V3 | |

前 4 脚顺序不变，**原来的 4 针 SWD 排线插 1–4 仍可用**。

脚 16/17 的重映射靠 `SYSCFG_CFGR1`（DS12992 Rev 3, Table 12 脚注 4）。

**为什么不上 USB**：STM32G031 **没有 USB 外设**（手册全文搜 USB 零命中，Development support
只写 "serial wire debug (SWD)"）。加 USB 要额外一颗 CH340/CP2102，45×22 mm 板上不划算。
调试用 SWD 就够：

| 方式 | 需要什么 | 说明 |
|---|---|---|
| **RTT**（推荐） | 只用 J3 的 1–4 脚 | `probe-rs` 支持 CMSIS-DAP 跑 RTT，直接读目标 RAM，**不停 CPU**，对 50 Hz 控制环无影响 |
| 串口 printf | J3 的 4/5 脚 + 任意 USB-TTL | 走 USART1 |
| 半主机 semihosting | 只用 J3 | 每次 printf 停 CPU，控制环会崩，**别用** |
| ~~SWO / ITM~~ | — | **Cortex-M0+ 没有**，M3 以上才有 |

### 舵机接口 —— 两套并存，⚠️ **脚序是相反的**

板上有四个舵机总线座子，两两一组，三根线一一并联（同一个电气节点），
**但两组的引脚顺序完全相反** —— 因为两家的线序本来就不同。

**`J1` / `J2` —— `B3B-EH-A`，2.5 mm，配 Dynamixel / 官方 HAT 线束**

| 脚 | 网络 |
|---|---|
| 1 | GND |
| 2 | VDD_BUS |
| 3 | **DXL_BUS** |

**`J4` / `J5` —— `B3B-PH-K-S`，2.0 mm，配飞特 HD-1910 线束**

| 脚 | 网络 |
|---|---|
| 1 | **DXL_BUS** |
| 2 | VDD_BUS |
| 3 | **GND** |

> ⚠️ **千万别照着 `J1` 复制网络给 `J4`。** 飞特《HD-1910-C001 串型规格书》A/0
> 第 3/7 页 6-7 项写明线端是 `1=Signal / 2=Vcc / 3=GND`，与 Dynamixel 侧头尾颠倒。
> 好在 **2.0 mm 与 2.5 mm 插不进对方**，物理上杜绝了插错，只剩「画错」这一种可能。
> 四个座子的脚序已于 2026-09-08 从 PCB 网表反读复核，全部落对。
>
> 另注意 **`AMP2.0` 是 2.0 mm、`JST EH` 是 2.5 mm**，飞特线插不进 `J1`/`J2`，
> 反之亦然 —— 用哪套舵机就插哪一组。

> 📌 **脚 3 此前本表误记为 `DXL_DATA`**。2026-09-06 补入 `R6` 150 Ω 串阻后，
> 缓冲侧（`DXL_DATA`）与连接器侧（`DXL_BUS`）已是两个网络，连接器上是 `DXL_BUS`。
> 2026-09-08 更正。

## 悬空脚

- U1：**3 (PC15-OSC32_OUT)、20 (PB3/PB4/PB5/PB6)**
  - 3 脚已引到焊盘，与 2 脚一起构成有源晶振预留位（默认不贴），见下方「时钟」
  - 20 脚是唯一完全空闲的 GPIO（并了 PB3/PB4/PB5/PB6 四个口，最灵活），留作后用
  - 1 脚 (PB7/PB8) 原本空闲，2026-09-07 起用作 `RX_EN`
  - 2 脚 (PC14-OSC32_IN) 接 `OSC_IN`、16/17 脚 (PA9/PA10) 接 `UART_TX`/`UART_RX`
    —— 此前本表误列为悬空，2026-09-07 更正
- U2：10 (OCS_Aux)、11 (SDO_Aux) —— 辅助 SPI 不用，ST DS13510 允许悬空；保守做法是 OCS_Aux 接 Vdd_IO

**U2.2 (SDx) 与 U2.3 (SCx) 必须接地**，不可悬空 —— ST DS13510 Rev 1, Table 1。

## 时钟：用内部 HSI16，晶振位预留不贴

**这个封装接不了无源晶振。** DS12992 Rev 3, Table 12 (p.36)：TSSOP20 的 2 脚
(`PC14-OSC32_IN`) 附加功能含 `OSC_IN`，但 3 脚 (`PC15-OSC32_OUT`) 只有 `OSC32_OUT`、
**没有 `OSC_OUT`**；`PF0`/`PF1` 在这个封装根本没引出来。无源晶振要两个脚才能起振。

| 方案 | 可行性 |
|---|---|
| 无源高速晶振 | ❌ 缺 `OSC_OUT` |
| 有源晶振走 HSE 旁路（灌进 2 脚，3 脚可作 `OSC_EN`） | ✅ |
| 32.768 kHz LSE 无源晶振 | ✅ 但不能给 PLL 供时钟，只能校准 HSI16 |

HSI16 精度（Table 41, p.64）：出厂 −0.75%/+0.5%，0–85 °C 温漂 ±1%，电压漂移 ±0.1%
→ 最坏约 **−1.85% / +1.55%**。1 Mbps UART 典型容差 ±3%，够用但余量不多。

**做法**：2、3 脚引到焊盘，留一个 3225 有源晶振位 + 去耦位，**默认不贴**。
实测通信有问题再贴 16 MHz 有源晶振。

## 使能极性说明

`1OE#` 低电平使能发送缓冲，`2OE` 接高电平使接收缓冲常开。

- PA1 是 USART2 的硬件 DE 脚，配置 `CR3.DEP = 1`（DE 低有效），收发切换由硬件完成
- 接收常开意味着发送时会在 RX 上收到自己的回显，固件按发送长度丢弃即可
- 备选方案是 `2OE` 也接 DE（发送时关掉接收缓冲），但那样发送期间 MCU 的 RX 脚悬空，重新使能时可能产生假起始位，不推荐
- **2026-09-07 改进**：`2OE` 不再硬接 +3V3，而是经 R7 10 kΩ 上拉、同时引到 `U1.1 (PB7/PB8)`。
  默认仍是常开（行为不变），但固件多了一个选项 —— 想关接收时拉低 PB7，并打开 MCU RX 脚的
  内部上拉解决浮空。比接 DE 更灵活：关不关、何时关，由固件自己定

## HD-1910-C001 实参（飞特官方产品页，预售期）

飞特为小鸭子专门做的一颗，页面标题即「**开源小鸭舵机** —— 串行总线舵机，专为小鸭子 AI 玩偶定制开发」。
舵机本体标注：**「三针接口 · TTL串行总线」**。

| 项 | 值 |
|---|---|
| 电压范围 | **5 V – 8.4 V** |
| 堵转扭力 | **10 kg·cm = 0.98 N·m** |
| 额定负载 | **3.0 kg·cm = 0.294 N·m** |
| 空载速度 | 0.09 s/60°（110 RPM） |
| **静态电流** | **21 mA** |
| **空载电流** | **140 mA** |
| **额定电流** | **500 mA** |
| **堵转电流** | **1.8 A** |
| 外观尺寸 | 34 × 20 × 23 mm |
| 重量 | 22.5 ± 2 g |
| 外壳 | PA + Fiber |

尺寸与 XL330（20×34×26 mm）同档，机械上近似可替换；扭矩比 XL330-M288（0.52 N·m）强近一倍。

> ⚠️ 别把 `HL-2915-C002` 规格书里的电气参数套到这颗上 —— 那是 12 V（9–14 V）机型。
> 可通用的只有连接器定义与协议部分。

### ⚠️ J1↔J2 直通路径的过流

J1 / J2 三根线一一并联，**本板若挂在链条中间，下游全部舵机电流都流经本板的连接器与铜箔**：

| 工况 | 单个 | ×15 |
|---|---|---|
| 静态 | 21 mA | 0.3 A |
| 空载转动 | 140 mA | 2.1 A |
| **额定负载** | **500 mA** | **7.5 A** |
| 堵转 | 1.8 A | 27 A |

而 **JST EH 额定电流仅 3 A**。

> F1（200 mA PPTC）**不受影响** —— 它只串在本板自取电那一路
> （`VDD_BUS → F1 → VDD_F → U4`），不在 J1→J2 直通路径上。

**二选一：**

1. **把本板挂在链条末端**（叶子节点），只用 J1，J2 空置或只接 1 个舵机 —— 流经本板的仅约 12 mA。**推荐**
2. 若必须置于链中，PCB 上 `VDD_BUS` 与 `GND` 从 J1 到 J2 走**大铜皮**（≥ 2 mm 或直接铺铜），
   并核算下游舵机数量不超过 3 A

## 飞特接口定义（官方规格书确认）

**来源**：飞特《HL-2915-C002 串型规格书》A/0，2026-02-27，第 4 页 6-7 项。

```
6-7  连接器和电缆 Connector and Cable
     类型 Type        AMP-3
     材质 Material    PP
     线长 Length      15CM / 25CM
     引脚定义         1  GND
     Pin Definition   2  Vcc
                      3  Signal/TTL
```

**`1=GND / 2=Vcc / 3=Signal`，与 Dynamixel 完全一致 → J1/J2 现有接法正确。**

关联证据：`HD-1910-C001.stp` 装配体里连接器零件名是 **`AMP-3P`**，且该装配体包含
`HL-2915-C002-20260409_ASM` —— 两款共用平台，接口定义通用。

### 同一份规格书里其它可用条目

| 项 | 值 | 意义 |
|---|---|---|
| 7-2 协议类型 | Half Duplex Asynchronous，**8bit / 1stop / No Parity** | 与本板一致 |
| 7-4 波特率 | 38400 ~ 1 Mbps，**出厂默认 1 Mbps** | 与 Dynamixel 同速 |
| 7-3 ID 范围 | 0–253，**出厂默认 ID 1** | 15 个舵机需逐个改 ID；本板用 200 不冲突 |
| 12 **信号高电平** | **2 V ~ 5 V** | 见下 |
| 12 信号低电平 | 0.0 V ~ 0.45 V | |
| 6-6 角度传感器 | 12 Bits 磁编码 | 磁编码 ⇒ **小端字节序** |

**信号电平两个方向都要看**：

1. 本板驱动总线 —— `SN74LVC2G241` 在 3.3 V 供电下输出约 3.3 V，落在舵机要求的 2–5 V 高电平窗口内 ✅
2. 舵机驱动总线 —— 它可能输出到 **5 V**；74LVC 在 3.3 V 供电时**输入耐 5.5 V** ✅
   （选 LVC 而非 LV/HC 正好卡住这条）

> ⚠️ 该规格书是 **HL-2915-C002（12 V，9–14 V）**，不是 HD-1910（5–8.4 V）。
> **电气参数不可混用** —— 供电范围、堵转电流、过压保护阈值都不同。
> 通用的只是**连接器定义与协议**部分。

### 背景：飞特不同系列的物理层不一样

官方各系列内存表手册（<http://doc.feetech.cn>，接口 `getQr/{q}`）原文：

| 系列 | 电平 | 默认波特率 |
|---|---|---|
| **STS**（磁编码） | **TTL 单总线** | **1M** |
| SCS（电位器） | TTL 单总线 | 1M / 500k |
| SMS（磁编码） | **RS485** | 115200 |
| HLS（磁编码） | 未注明 | 1M |
| SHC | CANopen | 125k |

「飞特 = TTL 单线」**只对 STS/SCS/HL 这一支成立**，SMS 是 RS485。换系列前先查它的手册。

## 协议自动识别（不用跳线、不用拨码）

两家包头天然可分，判别点是**第 3、4 字节**：

| | 包头 | 后续 | 校验 |
|---|---|---|---|
| Dynamixel V2 | `FF FF` | **`FD 00`** | CRC-16（poly 0x8005） |
| 飞特 STS/SCS | `FF FF` | `ID` + `LENGTH` | `~(ID+LENGTH+INST+参数)` |

无歧义：飞特包第 3 字节是 ID（可以是 0xFD），但**第 4 字节 LENGTH 永远不会是 0**
（最小为 2 = 指令 + 校验和）。所以 `FF FF FD 00` 只可能是 V2。

```
状态：未知 / 已锁 V1 / 已锁 V2

未知时，收到 FF FF 开头的包：
    if 字节[2]==0xFD && 字节[3]==0x00:
        按 V2 拆，算 CRC-16 → 过了记一票 V2
    else:
        按 V1 拆，算 ~sum   → 过了记一票 V1
    连续 3 票一致 → 锁定

锁定后：只按锁定协议解析，回复也用同一种
兜底：连续 100 包全解析失败 → 解锁重新识别
```

以下均以**飞特官方《舵机SCS通信协议》原文**为准：

- 帧格式：**1 起始位 + 8 数据位 + 无校验 + 1 停止位**，共 10 位
- 字头：连续两个 `0xFF`
- ID 范围 **0～253**（`0x00`～`0xFD`），**广播 ID = 254（`0xFE`）**
- 数据长度 **Length = 参数个数 N + 2**，所以**最小为 2，永远不会是 0** ← 判别无歧义的依据
- 校验和 = `~(ID + Length + Instruction + Param1 + … + ParamN)`，超 255 取低字节
- 同步读 `0x82`、同步写 `0x83`、PING `0x01`、读 `0x02`、写 `0x03`
- ⚠️ **多字节参数的字节序按舵机类型分**：「电位器类型舵机为**大端**（高字节在前），磁编码类型舵机为**小端**（低字节在前）」

三个要点：

1. **必须锁定，不能逐包判** —— 总线有噪声，某包被干扰成 `FD 00` 的样子会导致来回横跳
2. **回复用同一协议** —— 不只解析要分支，组包也要
3. **兜底解锁** —— 换舵机品牌时不必重烧固件

从机 ID 两边都用 **200**，与 15 个舵机（通常编 1–15）不冲突。

> 飞特 STS 的 `Return Delay Time` 默认 0，且手册标注 "Not functional on STS" ——
> 寄存器不生效，回复延迟完全由固件决定。

## 封装口径：阻容一律 0603

所有阻容用 **0603**，D2 用 **SOD-123**，不用 0402/SOD-323。

理由不是手焊 —— 板上有 LGA-14 的 LSM6DSV16X，本来就得上热风。
**真正的理由是调试期返修**：串阻从 150 Ω 试到 33 Ω、摘掉某个上拉、补一颗去耦，
0603 拿烙铁几秒就能改。第一版没验证过的板子必然要改几次。

代价：11 个器件多占约 16 mm²，不到板面积 2%。而且 0603 这几个值全在立创**基础库**
（10 kΩ `C25804` · 150 Ω `C22808` · 33 Ω `C23140` · 100 nF `C14663`），比 0402 的扩展库还省上料费。

> C6（10 µF/25 V）保持 0805；C5（4.7 µF）、C7（10 µF）本来就是 0603。

## 数据线保护（照 HAT 的做法）

```
U3.6 (1Y) ──┬─ DXL_DATA ─┬── R5 10k → 3.3V
U3.5 (2A) ──┘            │
                         └── R6 150Ω ──┬── DXL_BUS ── J1.3 / J2.3
                                       │
                                    D2 5V1
                                       ⏚
```

| 器件 | 作用 |
|---|---|
| **R6 150 Ω** | 源端串阻。限制短路电流、软化边沿降 EMI。1 Mbps 下延迟约占比特时间 3% |
| **D2 5V1** | 钳位。阴极接 `DXL_BUS`、阳极接地 |

**上拉留在缓冲侧**（R5 在 R6 之前）：这样即使不插总线，`U3.5 (2A)` 这个 CMOS 输入
也有确定电平，不会浮空。与 HAT 的 `R32` 位置一致。

> 官方 HAT 用的是 `R33 150R + TH1 100R` 串联共 250 Ω，外加 `D4 5V1` 钳位
> （`dynamixel.kicad_sch`）。**D2 与 HAT 的 D4 同型号、不同封装** —— HAT 是 SOD-323（`C151348`），本板用 SOD-123（`C151588`）便于返修。
> 本板只用 150 Ω，因为 HAT 侧已有 250 Ω，总线上串太多会拖慢边沿。

## 三道过压防线

1. **F1** PPTC 200mA 保持 / 24V —— 限流，防短路
2. **D1** TVS SMF12A —— 钳位，防舵机反电动势尖峰
3. **U4** HT7533-1 耐压 30V —— 即使前两道失效，LDO 本身扛得住

## 布局要点

- 2 层板，45 × 22mm，贴片件全在正面
- 3 个连接器（J1/J2/J3）排在同一条边，插件
- 两个 M2 安装孔，间距 34mm（与原版 `banana_pcb_locker` 兼容）
- C1/C2 紧贴 U2 的 Vdd / Vdd_IO 脚，走线尽量短
- C4（100nF）与 C5（4.7µF）紧贴 U1 的 4 脚 —— ST DS12992 Fig.13 要求"尽可能贴近引脚，或放在 PCB 背面正对该脚"
- DXL_DATA 走线加粗，远离 SPI

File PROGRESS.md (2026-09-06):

# 项目进度

**项目**：Microduck 复刻
**开始**：2026-08-28
**最后更新**：2026-09-03（硬件开源状态勘误：HAT 板官方已开源）
**仓库**：https://github.com/fanhao375/microduck-replica （公开）

---

## 目标

复刻 Pollen Robotics 的 **Microduck**（25cm 双足机器鸭，$399，2026 圣诞开卖）。
官方软件开源；硬件**部分开源** —— **HAT 板有完整 KiCad 工程与生产文件**
（[`elec_RPI_Robot_HAT`](https://github.com/pollen-robotics/elec_RPI_Robot_HAT)，Apache-2.0），
但 `imu_to_dxl` 板、可编辑机械 CAD、整机 BOM 与装配文档均未公开。

> **勘误 2026-09-03**：此前记录为「硬件不开源、无 PCB 原理图」，**判断错误**。
> 原因是只检索了 `microduck` 主仓，漏掉了同组织下 `elec_` 前缀的硬件仓库。

本项目从官方公开的 **MJCF 仿真模型 + 47 个 STL** 反推出机械复刻所需的全部信息。

---

## 总体状态

| 环节 | 状态 | 说明 |
|---|---|---|
| 零件几何 | ✅ 完成 | 47 个 STL |
| 装配关系 | ✅ 完成 | 精确到 0.1mm，已出爆炸图 |
| CAD 装配体 | ✅ 完成 | 已应用世界变换，可直接导入 |
| 关节参数 | ✅ 完成 | 14 个受控关节的轴线与行程 |
| 质量惯量 | ✅ 完成 | 15 个刚体 |
| 紧固件清单 | ✅ 完成 | 孔特征反推，M2 系统 |
| 执行器选型 | ✅ 完成 | XL330 ×15，BAM M6 参数 |
| 轴承规格 | ✅ 完成 | Ø22×16×4、Ø15×10×3 |
| **电控方案** | ✅ 完成 | 从 Rust 源码完整还原，见「第 6 批」 |
| 主控选型 | ✅ 完成 | **Radxa Zero 3W 市售模块**，非定制载板 |
| **HAT 板** | ✅ 官方已开源 | KiCad + Gerber + BOM + 贴片坐标，直接打样（4 层板） |
| **`imu_to_dxl` 板** | ✅ 已自绘（未打样） | 全网无公开工程；芯片/地址/协议已完整还原，本仓库提供原理图 + PCB |
| **走线方案** | ❌ 缺失 | 官方无任何资料 |
| **控制软件** | ✅ 可用 | 主控同款则官方 Rust 运行时直接跑；换主控才需移植 |
| **策略重训** | ✅ 非必需 | 硬件同款则官方 9 个 ONNX 直接可用；改本体/电控才需重训 |

---

## 已完成

### 第 1 批 · 资料摸底

- ~~确认 **Microduck 硬件不开源**~~：`microduck` 仓库全是 Rust 软件，
  `docs/` 下 5 个子目录全是软件文档，全库搜不到任何 `.stl/.step/.f3d/bom` 文件
  —— **这条结论下错了**（2026-09-03 更正）。只查了主仓，没查同组织下 `elec_` 前缀的
  硬件仓库；**HAT 板在 [`elec_RPI_Robot_HAT`](https://github.com/pollen-robotics/elec_RPI_Robot_HAT)
  里是完整开源的**（Apache-2.0，含 KiCad + Gerber + BOM + 贴片坐标）。
  教训：判断「某项目有没有开源某部分」时，必须检索**整个组织**，不能只看主仓。
- 确认 **`microduck_rl` 里有 47 个 STL + 完整 MJCF**，这是唯一的几何来源
- 确认 **3D 模型许可证是 CC BY-NC-SA**（非商用），代码是 Apache-2.0
- 排除了 Open Duck Mini v2 路线（见「决策记录」）

### 第 2 批 · 装配图

- 用 MuJoCo 离屏渲染，白色天空盒，1600×2100
- 4 张常规视图 + 2 张爆炸图 + 1 张分色对照图
- 爆炸图沿运动学链逐级偏移（每级 48mm），越靠链末端炸得越远
- 自己实现了世界坐标→像素的投影，用于画标注引线与避让排版
- 产出：`assembly-drawings/`（7 张），脚本 `scripts/render_assembly.py`

### 第 3 批 · CAD 装配体

- 上游 47 个 STL 都是**零件自身坐标系**，直接导入 CAD 会全部堆在原点
- 从 MJCF 取每个 geom 的世界变换，应用后按刚体分组导出
- 产出：`cad/` —— 整机单文件（796792 三角面）+ 15 个部件，单位 mm
- 整机实测外形 **144 × 141 × 264 mm**（与官方标称 25cm 吻合）
- 脚本 `scripts/export_assembly_stl.py`

### 第 4 批 · 紧固件反推

- 写了孔特征识别：焊接顶点 → 建面片邻接图 → 按二面角 35° 切割光滑曲面片
  → 每片拟合圆柱（轴 = 法向协方差最小特征向量）→ 投影拟合圆求直径
  → 按法向朝向判别孔/凸台
- 47 个零件扫完耗时 2.5 秒
- 产出：`docs/紧固件反推.md`、`docs/hole_analysis.json`、`scripts/analyze_holes.py`

### 第 10 批 · 英文文档

- 背景：awesome 列表收录时特意标注 "In Chinese"；流量数据显示 Google 仅 5 次
  而 Bing 132 次，英文圈基本没进来
- 按访问量定优先级，先翻 `硬件方案逆向.md`（站内访问第 2，84 次），
  因为它是**全网独有内容** —— HF 员工 @mishig25 做的 3D 解剖页（3.6 万浏览）
  已覆盖「整机长什么样」那一层，规格类文档与其重合，而芯片地址、总线协议、
  12 字节数据块布局这些只有本仓库有
- 产出：`docs/hardware-teardown.en.md`（426 行）+ `docs/actuator-selection.en.md`（459 行），
  均与中文版互相链接
- 英文 README 的文档索引改为用 🇬🇧 标记哪些有英文版

### 第 9 批 · 执行器选型分析

- 回答两个高频问题：为什么用舵机不用闭环步进；能不能不改机械件换成便宜的 STS3215
- **硬数据对照**：同为 15 刚体双足鸭，XL330 版 **737.2 g** vs STS3215 版 **2107.1 g**，
  差 2.86 倍 —— Open Duck Mini v2 就是「STS3215 版的答案」（42cm / 2.1kg）
- **执行器参数对照**：kp 差 32×、forcerange 差 3.5×、damping 与 frictionloss 各差 11×、
  armature 差 15.5× —— 每一项都差一个数量级
- 反直觉发现：XL330 建模的回差反而更大（±1.0° vs ±0.5°）
- 结论：**没有中间路线** —— 保 XL330（舵机 ¥4500）或换 STS3215
  （等于去做 Open Duck Mini v2）
- **补充同级别舵机横向对比**：飞特 STS3032（20 g / 23.2×12.1×28.5 mm / 0.44 N·m /
  4.8–6 V）尺寸比 XL330 还小、重量相当，但力矩约 85%（同电压口径）且电压上限 6 V；
  SCS0009 仅 11 g 但只有 0.23 N·m（Pollen 自己用在 Amazing Hand 上）
- 结论：空档明确为「18–20 g / ≥0.9 N·m / 7.4 V / 总线」，目前只有 Robotis 一家满足
- **深度评估宇树 S288**（通读官方 11 页手册）：19.5 g / 34×20×23 mm /
  **减速比 288.35:1 与 XL330 完全相同** / M2 固定 / 单线半双工 —— 机械上几乎是平替
- S288 的两个实质升级：**阻抗控制**（τ = τ_ff + k_p·Δp + k_d·Δω）和
  **输出端编码器**（OutPos 13 位）—— 后者可直接消灭回差建模的整套复杂度
- S288 的三个硬约束：电压 12.6 V (3S) vs Microduck 的 7.4 V (2S)；
  总线地址空间仅 0~14 装不下第 16 个设备（IMU 须另走 SPI）；
  **力矩标注存疑**（转子端/输出端两种解读都说不通），已列出向厂商求证的四个问题
- 产出：重写 `docs/执行器选型.md`（106 → 424 行）

### 第 8 批 · X 社区情报与外部验证 ⭐

- 通过 opencli 的 twitter read 命令（search / thread）读取 X 公开帖
- **核心收获：逆向结论获得外部独立验证** —— @tspy 的硬件拆解（169 赞）
  独立列出 Radxa ZERO 3W / RK3566，与本仓库完全一致
- 记录热度数据：官方三条推合计约 860 万浏览；GitHub 三天涨 3.7 倍
- 记录社区已做出的二次开发（R2D2 语音合成、激光笔追踪、翻筋斗、霹雳舞）
- **识别并标注噪音**：大量 meme 币蹭热度；「Microdino」经查回复区
  充斥 scam 指控且 CAD 问题含糊其辞，**判定为不可信，不予引用**
- 明确一个前提：**截至 8/31 市面无实物**，所有公开 teardown 都是推理而非物理拆解
- 产出：`docs/社区动态.md`（150 行）

### 第 7 批 · 官方规格交叉验证 + 社区动态

- 官方 2026-08-27 发布，公布部分规格；与本仓库逆向结果**逐项对照**
- 互相印证：RK3566 / NP-F550 / 8×8 ToF / 宽 140mm 全部对上
- 官方补足：RAM 1GB + 32GB eMMC（**正是 Radxa Zero 3W 的 SKU，反向佐证主控判断**；源码中无佐证，复刻建议 2G/16G）、
  NPU 0.8 TOPS、NFC 双天线
- 逆向独有：主控型号、主总线方案、全部芯片地址与协议
- **发现一处矛盾**：官方标 2 个 IMU，源码里只有 1 个在用（BMI088 标注 dormant）
- 记录官方开源立场：Pollen 明确要求媒体**不要**称其为"开源硬件"（但加了 "for now"）
- 记录社区三个未获回复的 issue（#175 STEP / #173 打印源文件 / #174 电源板原理图）

### 第 6 批 · 硬件方案逆向 ⭐

- 思路：**运行时要驱动真实硬件，就必须写死设备路径、I2C 地址、寄存器偏移、
  波特率和协议 —— 代码即规格书**
- 从 `duck-control/src/{model,imu,bus}.rs`、`deploy/*.dts`、`deploy/robotd.toml`、
  `tof/`、`mediad/` 里逐项挖出完整电控方案
- 产出：`docs/硬件方案逆向.md`（394 行，完整推导）+ `docs/硬件规格速查.md`（270 行，一页纸速查）

### 第 5 批 · 执行器选型

- 整理 BAM M6 配置、三项域随机化范围、回差编码器建模
- 提取 `joints_properties.xml` 里 5 组 BAM 实测标定的原生 PD 参数
- 产出：`docs/执行器选型.md`

---

## 关键发现

1. **整机是 M2 螺丝系统。**
   Ø2.2 过孔 ×77、Ø4.4 沉头孔 ×28、Ø1.6 攻丝底孔 ×20。
   Ø2.2 与 Ø4.4 成对出现 = M2 内六角柱头的过孔+沉孔组合。
   交叉验证：`xl330.stl` 自身是 Ø2.0×4 + Ø1.6×8，与 XL330 的 M2 安装孔一致。
   结构件过孔约 **146 个**。

2. **是 15 个舵机，不是 14 个。**
   `xl330` 网格在整机 MJCF 中被引用 **15 次**。14 个进策略动作空间
   （左腿 5 + 颈头 4 + 右腿 5），第 15 个驱动喙/下颚，走 `passive_*` 连杆。
   这与官方 README 的 "15 servos" 一致 —— 只数关节列表会漏掉。

3. **头部占整机四分之一重量。**
   躯干 199g，头部总成 189g，整机 737g。重心很高，
   这解释了为什么它的行走策略难训。

4. **回差建模是 sim2real 的关键细节。**
   真实舵机磁编码器在齿轮间隙的**输出侧**，固件位置环闭环在
   `主关节角 + 回差角` 上；舵机在死区空转时测到的位置不变，PD 误差也不变。

5. **自己造比买贵。**
   15 个 XL330 按渠道从 $359（ROBOTIS 国际站）到 €629（MyBotShop）不等，
   即从略低于到远超整机 $399 售价。核价见 BOM.md。

6. **⭐ 主控是市售模块，不是定制载板 —— 此前判断有误。**
   （2026-08-31 补充：此结论已获 X 上 @tspy 的独立拆解验证）
   设备树里写死 `compatible = "radxa,zero-3w", "rockchip,rk3566"`，
   就是市面上能买到的 **Radxa Zero 3W**（Pi Zero 形态，65×30mm，与 STL 吻合）。
   这直接推翻了「电控是硬墙」的结论。

7. **IMU 挂在 Dynamixel 总线上，不走 I2C。**
   自制 `imu_to_dxl` v2 板：LSM6DSV16X，总线 ID 200，寄存器 124，12 字节块
   （陀螺 6 字节 + SFLP 四元数 fp16 6 字节）。和 15 个舵机在**同一次 sync_read**
   里读回，零额外总线开销，主机不用跑姿态融合。

8. **没有电量计，没有 ADC。**
   电池电压直接读舵机通过 Dynamixel 报告的自身供电电压。
   所以 6.6–8.2V 是「带载可用区间」而非电芯量程。复刻时**不需要设计任何电池监测电路**。

---

## 决策记录

| 决策 | 结论 | 理由 |
|---|---|---|
| 做 Microduck 还是 Open Duck Mini v2 | **做 Microduck** | 用户明确要 Microduck 本身。Open Duck Mini v2 虽然全套开源（BOM/CAD/STL/装配指南齐全），但那是另一台机器人 |
| 仓库公开还是私有 | **公开** | 用户选择。CC BY-NC-SA 允许转发，已配好署名、同协议、非商用声明 |
| 是否把 6 个上游仓库一起打包 | **不打包** | 重新托管别人的代码不合适，且会丢失上游更新。改用 `scripts/fetch_upstream.sh` + 链接<br>（2026-09-04 补充：`print/` 是有意的例外 —— 单件 STL 是复刻者最需要能在网页上逐个查看的东西，CC BY-NC-SA 允许再分发，已在 NOTICE.md 声明） |
| 许可证 | **双协议** | `scripts/` 原创 → Apache-2.0；`assembly-drawings/` `cad/` 是 CC BY-SA-NC 衍生作品 → 依 ShareAlike 沿用同协议 |
| 遇到 PCB 这堵墙怎么办 | **机械照抄 + 电控自建** | 100% 复刻不可能。用户表示能自己做 PCB，所以这条路可行 |

---

## 下一步待办

### 优先级 高
- [x] **画 `imu_to_dxl` 板** —— **原理图与 PCB 都已完成**（2026-09-07）。
      STM32G031F8P6 + LSM6DSV16X + SN74LVC2G241 半双工缓冲；
      45 × 22 mm 双层板，底层整片 GND，22 个网络全通、DRC 0 违规。
      **未打样、无实物验证** → [工程与复查结果](hardware/imu_to_dxl/)
- [ ] **`imu_to_dxl` 打样验证** —— 下单前先跑器件标准化、复核丝印；
      连接器高度（直插 8 mm vs 躯干内腔）需用 STEP 在装配体里确认
- [x] ~~**PCB 板框反推**~~ —— **已作废**：官方 KiCad 工程与 Gerber 直接提供精确板框、
      孔位与连接器开口，无需从 STL 反推
- [ ] **决定 HAT 板做不做** —— 不要录音/喇叭的话可完全省略，
      ToF 直接挂 i2c3，电源用现成 UBEC

### 优先级 中
- [x] ~~英文化~~ **已完成**：硬件方案逆向 / 执行器选型 / 紧固件反推 三份全部英文化，
      加上 README 共 4 份双语。`社区动态.md` 与 `PROGRESS.md` 不翻 ——
      前者时效性强会过期，后者是内部进度
- [ ] `硬件规格速查.md` 暂不翻 —— 与 @mishig25 的 3D 解剖 Space 内容重合度高
- [ ] **STL 可打印性检查** —— 验证 47 个网格是否水密、是否有非流形边，
      判断能否直接切片
- [ ] **打印工艺评估** —— 仿真网格无配合公差，需评估哪些孔位要放量、
      哪些面需要支撑
- [ ] **走线通道分析** —— 从装配体的内部空腔反推可行走线路径

### 优先级 低
- [ ] **控制软件方案** —— Rust 运行时绑定 RK3566，评估移植成本
      vs 用 Python 重写控制循环
- [ ] **策略重训** —— 换电控后官方 ONNX 失效，需用 `microduck_rl` 重训
      （需 CUDA GPU，或用 `--hf-jobs` 跑在 HuggingFace 上）

---

## 风险与已知局限

1. **仿真 STL ≠ 可打印工程件。** 仿真只保证外形与惯量，不保证配合公差、
   螺纹孔、热熔螺母座、走线空间。直接打印大概率装不起来。
2. **紧固件是反推的，不是图纸。** 螺丝长度按孔深推算，是区间不是实测值。
   打印收缩还会改变实际孔径（FDM 上 Ø2.2 通常偏小 0.1–0.3mm）。
3. **`imu_to_dxl` 板需自绘。** 全网无公开工程，只能照还原出的协议自己设计。
   （HAT 板官方已开源，含 Gerber，**不构成阻塞**。）
4. **官方策略不可迁移。** 换电控后 9 个 ONNX 全部失效，必须重训。
5. **非商用限制。** 所有几何衍生内容受 CC BY-SA-NC 约束，不得用于商业产品。

---

## 文件索引

| 路径 | 内容 |
|---|---|
| `README.md` | 项目总览、装配结构、关节参数、可行性分析 |
| `PROGRESS.md` | 本文档 |
| `NOTICE.md` | 署名与来源 |
| `assembly-drawings/` | 7 张装配图 |
| `cad/` | 16 个 STL（整机 + 15 部件）+ 零件对照表 |
| `docs/紧固件反推.md` | M2 螺丝系统、采购量、轴承规格 |
| `docs/执行器选型.md` | XL330 参数、BAM M6、5 组标定 PD、回差建模 |
| `docs/硬件规格速查.md` | 一页纸硬件规格表 |
| `docs/硬件方案逆向.md` | 电控方案完整推导与证据 |
| `docs/社区动态.md` | X / GitHub 情报、外部验证、噪音与风险 |
| `docs/hole_analysis.json` | 孔扫描原始数据 |
| `scripts/` | 拉上游 / 渲染 / 导出 CAD / 扫孔，4 个脚本 |

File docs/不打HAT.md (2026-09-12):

# 不打 HAT · 用 ¥70 的模块飞线替代

**简体中文**

> 官方 HAT 是 4 层板、双面贴装、110 个器件 —— 打样贴片一次上千块，**很多人觉得划不来**。
> 这份就是替代方案：一个降压模块 + 一个半双工转接板，剩下的飞线。**功能上只少了板载音频和关机检测信号。**

先看 [硬件入门](硬件入门.md) 知道 HAT 本来干什么，再看这份知道怎么不用它。

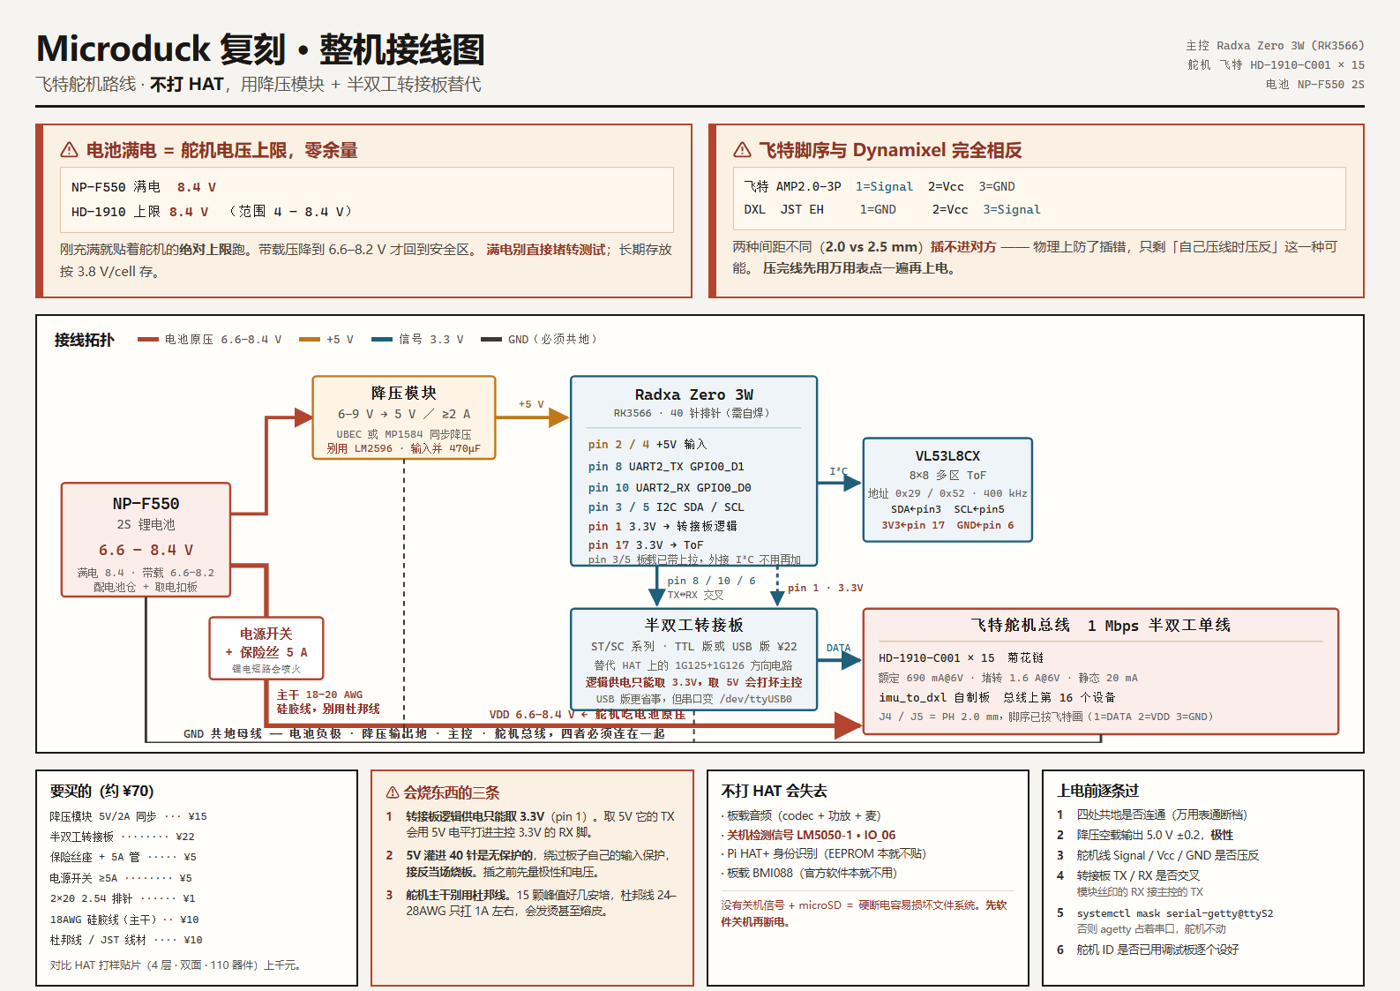
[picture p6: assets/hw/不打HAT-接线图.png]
不打 HAT 接线图


> **图的源文件是 [`不打HAT-接线图.html`](不打HAT-接线图.html)** —— 内联 SVG，下载后浏览器打开，能缩放、能选字、能打印 A3。
> 换模块、换脚位直接改它。上面这张 PNG 只是 GitHub 里的预览。

**目标**：主控从电池取电、经转接板跟舵机总线通信、ToF 挂上 I²C —— **不打 HAT 板**，¥70 的模块顶替上千块的打样。

> ⚠️ **这一章是计划，还没做过。** 接线部分来自规格书和官方原理图，软件部分来自官方 `setup-board.sh` 的源码。
> 做的时候哪步不对就改这里。做完把「没做过、要验证的」那节清掉。

## 要买什么

淘宝链接会失效，**搜索词和要看的数不会**。每行按「搜索词」搜，按「买之前看」挑。找到合适的把链接贴到 [电控采购清单](电控采购清单.md) 里。

| 东西 | 搜索词 | 买之前看 | 约价 |
|---|---|---|---|
| **降压模块** | 「UBEC 5V 3A 2S」 | **输入下限 ≤ 6 V**（很多标 2–6S 的实际 7 V 起，2S 快没电先掉出稳压）· 输出 ≥ 2 A 连续 · 同步降压，**别买 LM2596** | ¥10–15 |
| **半双工转接板** | 「串口总线舵机驱动板 ST SC」 | TTL 版或 USB 版都行。**逻辑供电范围含 3.3 V**（有的只吃 5 V，那就不能接主控）· 舵机侧电源能过 8.4 V | ¥22 |
| 2×20 排针 | 「树莓派 彩色排针 2x20」 | 2.54 mm · 立式 · 彩色的好数脚 | ¥1 |
| 高耐久 microSD ×2 | 「SanDisk 高耐久 64G」或「海康 PLUS 64G」 | **京东自营** · 标 High Endurance / 监控专用 · **不是** Ultra / EVO 那种普通卡 | ¥90×2 |
| 读卡器 | 「USB3.0 读卡器 TF」 | USB 3.0 | ¥15 |
| 硅胶线 | 「18AWG 硅胶线 红黑」 | 18 或 20 AWG · 硅胶皮（软，耐温）· 红黑各 1 m | ¥10 |
| 保险丝座 + 管 | 「5x20 保险丝座 带线」+「5A 保险丝 5x20」 | 座子带线的省焊 · 快熔 5 A | ¥5 |
| 电源开关 | 「船型开关 KCD1」 | 额定 ≥ 6 A · 单刀单掷就行 | ¥3 |
| PH2.0 3P 端子线 ×5 | 「PH2.0 3P 端子线 单头」 | 2.0 mm 间距 · 3 针 · 单头带线（另一头裸线） | ¥5 |
| 杜邦线 | 「杜邦线 母对母 20cm」 | 母对母 · 20 cm · 一排 40 根 | ¥5 |
| 470 µF 电解 | 「470uF 16V 电解电容」 | 16 V 或以上 · 105 ℃ | ¥1 |
| *（可选）USB 声卡* | 「USB 声卡 免驱 3.5mm」 | **免驱**（Linux 认 UAC 标准）· 带麦克风口 | ¥15 |
| *（可选）小喇叭* | 「3W 4欧 小喇叭」 | 4 Ω 3 W · 接声卡的 3.5 mm 口要经功放，或直接买带功放的 USB 小音箱 | ¥5 |

不打 HAT 会失去：**关机检测信号**（LM5050-1 IO_06）、板载 BMI088（官方软件本就不用）、**板载音频** —— 音频可以用 USB 声卡补回来，见第 8 步。
没有关机信号 + microSD = 硬断电伤卡，**先软件关机再断电**。

## 第 1 步 · 主控点亮，什么都别接

```
1  焊排针 —— 先焊对角两针，翻过来看立直了没，再焊其余 38 个
2  下 Armbian：官方目标是 Armbian 26.2.x（install.sh 第 7 行），Radxa Zero 3 的 headless/minimal 镜像
3  balenaEtcher 或 dd 烧到 microSD
4  插卡，USB-C 供电（先用 USB，别用飞线的 5 V）
5  路由器里找到它的 IP，ssh 进去（Armbian 首次登录会让你设密码、建用户）
```

点亮了再往下。**点不亮的问题别跟接线的问题混在一起。**

## 第 2 步 · 让 `/dev/ttyS2` 出现

**这是不打 HAT 最容易卡住的地方。** Armbian 出厂设置下 `/dev/ttyS2` 根本不存在，板子却一切正常，你会以为是线接错了。

官方 `setup-board.sh` 做四件事，你可以直接跑它，也可以手工做：

```bash
# ① overlay 前缀 —— Armbian 出厂写的是 rk35xx，但 RK3566 的 overlay 文件叫 rk3568-*.dtbo
#    前缀错了加载器什么都找不到，静默失败
sudo sed -i 's/^overlay_prefix=rk35xx$/overlay_prefix=rk3568/' /boot/armbianEnv.txt

# ② 开 uart2 的 M0 引脚复用 —— 这就是 40 针的 pin 8 / pin 10
echo 'overlays=uart2-m0' | sudo tee -a /boot/armbianEnv.txt

# ③ 内核 console 默认占着 ttyS2（它是 RK3566 的调试串口）—— 从 /boot/armbianEnv.txt 的
#    extraargs 里把 console=ttyS2,1500000 拿掉，不然内核往舵机总线上打日志

# ④ 登录控制台也占着它
sudo systemctl mask serial-getty@ttyS2

sudo reboot
ls -l /dev/ttyS2          # 出现了才算过
fuser -v /dev/ttyS2       # 应该什么都不占
```

⚠️ **`apt upgrade` 换内核后可能把 ① 打回原形。** 舵机突然全不动了，先看这条。

直接跑官方脚本的话（上游仓库是公开的，不用 token）：

```bash
git clone https://github.com/pollen-robotics/microduck
sudo sh microduck/scripts/setup-board.sh    # 幂等，不自动重启
sudo reboot
```

## 第 3 步 · 电源，每接一段量一次

```
NP-F550 ──► 开关 ──► 保险丝 5A ──┬──► 降压模块 ──► 5 V ──► Radxa pin 2（或 4）
                                 │        │
                                 │        └── 输入端并 470 µF
                                 │
                                 └──► 舵机总线 VDD（原压，18 AWG）
共地：电池负极 · 降压输出地 · Radxa pin 6 · 舵机总线 GND
```

```
1  接开关、保险丝，量：开关闭合时保险丝两端应导通
2  接降压模块，先别接 Radxa，量输出：5.0 V ±0.2，极性对
3  ⚠️ 确认极性再插 Radxa —— pin 2/4 是无保护的，接反烧板
4  Radxa 拔掉 USB-C，靠 pin 2 的 5 V 点亮，ssh 能进
5  再接舵机总线的 VDD
```

## 第 4 步 · 舵机总线接主控

```
Radxa 40 针                     转接板 MCU 侧
pin 1   3.3 V    ──────────►   VCC       ⚠️ 只能 3.3 V，接 5 V 它的 TX 会打坏主控 RX
pin 8   UART2_TX ──────────►   RX        ← 交叉
pin 10  UART2_RX ◄──────────   TX        ← 交叉
pin 6   GND      ──────────►   GND

转接板舵机侧
DATA  ──► 舵机总线 S
V     ◄── 舵机总线 VDD（电池原压，第 3 步接的）
G     ──► 共地
```

**USB 版转接板**：不用接 pin 1/8/10，插 Radxa 的 USB 口，串口变成 `/dev/ttyUSB0`，
之后 `robotd.toml` 里 `port = "/dev/ttyUSB0"`。省事，但第 2 步的 ttyS2 就用不上了。

## 第 5 步 · 一颗舵机验证通信

只挂**一颗**配好 ID 的舵机（比如左膝 23），主控上：

```bash
# 官方运行时带的总线基准工具（第 7 步装完才有），或先用 Python 快速 ping：
pip install feetech-servo-sdk    # 或 scservo_sdk
# 1 Mbps，ping ID 23 —— 回了就通了
```

不通按顺序查：`ls /dev/ttyS2` 有没有 → `fuser` 有没有人占 → TX/RX 是不是交叉 → 转接板 VCC 是不是 3.3 V → S 线接触。

## 第 6 步 · ToF

```
VL53L8CX          Radxa 40 针
SDA      ◄──►    pin 3
SCL      ◄──►    pin 5
3V3      ◄───    pin 17     （pin 1 给转接板了，分开用）
GND      ────►   pin 6
```

pin 3/5 板载带上拉，不用外加。

⚠️ **I²C 还要一个 overlay。** 官方是 `i2c3` 重 mux 到 M0（就是 pin 3/5），代价是失去 USB-C PD 协商。
官方的 overlay 在 `deploy/audio/i2c3-pihat.dts`，是给 HAT 写的，**不打 HAT 能不能直接用，待验证**。

## 第 7 步 · 跑官方运行时

```bash
curl -fsSL https://raw.githubusercontent.com/pollen-robotics/microduck/main/scripts/provision.sh -o /tmp/provision.sh
sudo sh /tmp/provision.sh
# = setup-board.sh → migrate-network.sh → 重启 → install.sh，全自动
robotctl health
```

`robotd.toml` 在 `/etc/robot/`，串口默认 `/dev/ttyS2`，USB 版转接板改成 `/dev/ttyUSB0`。

## 第 8 步 · 想要声音（可选）

不打 HAT 就没有 codec，官方的叫声、摸头识别、ToF 电子琴、多鸭合唱都用不了 —— **但机器人走路不受影响**，官方注释原话「没有 codec 的板子走路完全一样，只是不出声」。

想要回来，插个 **USB 声卡**（免驱那种，Linux 直接认）：

```bash
aplay -l                          # 看到 USB Audio 那张卡的名字，比如 card 1: Device
sudo nano /etc/robot/robotd.toml
```

```toml
[audio]
enabled = true
device = "plughw:CARD=Device"     # 换成 aplay -l 看到的名字，官方默认是 plughw:aic3104
```

```bash
sudo systemctl restart robotd
```

喇叭接声卡的 3.5 mm 口（小喇叭要功放，直接买带功放的 USB 小音箱最省事），麦克风接声卡的 mic 口。

⚠️ **没验证过**：官方 `sounds` 和 `pet_detect` 是按 aic3104 的采样率和通道数写的，USB 声卡不一定对得上。跑通了把这条改掉。

## 没做过、要验证的

| 项 | 疑问 | 怎么验 |
|---|---|---|
| 第三方转接板 @ 1 Mbps | 官方 HAT 的方向电路是 `1G08+1G125+1G126`，¥22 的板子方向切换够不够快 | 第 5 步通了、`bench_dynamixel_bus` 错误计数为 0 |
| `i2c3-pihat.dts` 不打 HAT 能不能用 | 那个 overlay 是给 HAT 写的 | 第 6 步 `i2cdetect -y 3` 看到 0x29 |
| 降压模块扛不扛得住舵机启动压降 | 15 颗同时动电池会跌 | 走路时主控不重启；不行就加大输入电容 |
| Armbian 具体哪个镜像 | 官方说 26.2.x，没说 minimal 还是 desktop | 第 1 步能 ssh 进去就行 |
| USB 声卡能不能替代 aic3104 | 官方音频代码按 codec 的采样率写的 | 第 8 步 `robotctl health` 音频那行不报错、开机有叫声 |

接线图见文首，源文件是同目录的 `不打HAT-接线图.html`。

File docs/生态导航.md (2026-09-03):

# Microduck 生态导航

**简体中文** · [English](ecosystem.en.md)

Microduck 的东西散在 GitHub 好几个组织和 HuggingFace 三种资源类型里，
**官方硬件仓库尤其容易被漏掉**（不在主仓，前缀是 `elec_`）。

这份索引说清楚每个东西**是什么、能拿来干嘛**。数据截至 **2026-09-04**，星数会变。

---

## 一、官方仓库（pollen-robotics）

### 核心两个

| 仓库 | 星 | 许可 | 这是什么 |
|---|---|---|---|
| [**microduck**](https://github.com/pollen-robotics/microduck) | 6982 | Apache-2.0 | **板载运行时**。Rust 写的，跑在机器人上的全部软件：50Hz 控制环、更新器、BLE、摄像头/WebRTC、ToF、语音。想读硬件规格也看这里 —— 设备路径、I²C 地址、寄存器全写死在代码里 |
| [**microduck_rl**](https://github.com/pollen-robotics/microduck_rl) | 1668 | Apache-2.0 | **强化学习训练环境**（基于 mjlab）。**47 个 STL 和完整 MJCF 在这里**，是所有几何信息的唯一来源 |

### 硬件（容易被漏的两个）

| 仓库 | 星 | 许可 | 这是什么 |
|---|---|---|---|
| [**elec_RPI_Robot_HAT**](https://github.com/pollen-robotics/elec_RPI_Robot_HAT) | 15 | Apache-2.0 | ⭐ **HAT 板的完整开源工程**。KiCad 9 原理图与 PCB、Gerber、BOM、贴片坐标、STEP、全套器件手册。**这块板不用自己画，下载 `production/` 直接打样**（4 层板） |
| [**lib_KiCAD**](https://github.com/pollen-robotics/lib_KiCAD) | 3 | — | Pollen 的 KiCad 符号/封装/3D 模型库。**打开上面那个工程必须先装它**，否则一片未解析符号 |

> 很多人以为「Microduck 硬件没开源」——**HAT 板其实是开源的**，只是不在主仓。
> 真正没公开的是 `imu_to_dxl` 板、可编辑机械 CAD 和整机 BOM。

### 配套

| 仓库 | 星 | 这是什么 |
|---|---|---|
| [rustypot](https://github.com/pollen-robotics/rustypot) | 56 | Dynamixel 通信库（Rust）。运行时靠它跟舵机说话，`xl330.rs` 里是完整寄存器表 |
| [microduck-gst-plugins](https://github.com/pollen-robotics/microduck-gst-plugins) | 13 | 预编译的 aarch64 GStreamer 插件：Rockchip MPP 硬件编码器 + WebRTC |
| `duck_detector` | — | ⚠️ **不公开**（404）。NPU 检测模型的训练仓库，官方文档里引用了它，但外部访问不到 |

---

## 二、HuggingFace

### 模拟器与可视化

| 名称 | ♥ | 说明 |
|---|---|---|
| [**pollen-robotics/microduck-simulator**](https://huggingface.co/spaces/pollen-robotics/microduck-simulator) | **374** | ⭐ **官方网页模拟器，打开就能玩**，不用装任何东西。想先感受一下就从这开始 |
| [mishig/microduck-anatomy](https://huggingface.co/spaces/mishig/microduck-anatomy) | 6 | 结构解剖可视化，HF 员工做的 |
| multimodalart/microduck-ar | 1 | AR 查看 |
| AlexWortega/microduck-vla-simulator | 0 | VLA（视觉-语言-动作）模拟 |

### 策略模型

| 名称 | ♥ | 说明 |
|---|---|---|
| [**pollen-robotics/microduck-policies**](https://huggingface.co/pollen-robotics/microduck-policies) | 8 | ⭐ **官方 9 个 ONNX 策略**。硬件同款即可直接用，不用重训 |
| [RemiFabre/microduck-flamingo-cycle](https://huggingface.co/RemiFabre/microduck-flamingo-cycle) | 21 | Rémi 本人发的，单脚站立循环 |
| RemiFabre/microduck-rough-walk-e / -g | 1 | 崎岖地面行走 |

社区还有一批动作策略：`happy-hop`（跳）、`polite-bow`（鞠躬）、`moonwalk-backward`（太空步）、
`beak-throw`（用喙抛物）、`electric-slide`、`swing`（荡秋千）、`stilts`（高跷）、`running`。

> 上游给了 `uv run publish` 一条命令，可以把自己训的策略直接发到 Hub。

### 数据集（最近才开始出现）

| 名称 | 更新 | 说明 |
|---|---|---|
| [craigm26/microduck-stairs-challenge](https://huggingface.co/datasets/craigm26/microduck-stairs-challenge) | 09-02 | 爬楼梯挑战 |
| craigm26/microduck-ball-challenge | 09-02 | 追球 |
| allen73/microduck-trajectory-dataset | 09-02 | 轨迹数据 |
| devorah-ai-2026/microduck-locomotion-dataset-v1 | 09-03 | 运动数据 |
| pngwn/microduck-detection-dataset | 09-03 | 目标检测 |
| craigm26/microduck-policy-golden-vectors | 08-31 | 策略回归测试的黄金向量 |

> 数据集集中出现在 9 月初，是社区**从「玩」转向「训」**的信号。

---

## 三、社区项目

### 工具与框架

| 仓库 | 星 | 这是什么 |
|---|---|---|
| [rokbenko/quackd](https://github.com/rokbenko/quackd) | 139 | 给小机器人接大脑，用自然语言指挥 Microduck / Open Duck Mini |
| [jonathanhawkins/microduck-lab](https://github.com/jonathanhawkins/microduck-lab) | 73 | **在普通 Mac 上训 RL 策略，不需要 CUDA** |
| [joeynyc/awesome-microduck](https://github.com/joeynyc/awesome-microduck) | 67 | 英文 awesome 列表 |
| [craigm26/duckkit](https://github.com/craigm26/duckkit) | 6 | 纯 Swift 实现，真策略真运动学 |
| [aj-dev-smith/microduck-mcp](https://github.com/aj-dev-smith/microduck-mcp) | 2 | 用 MCP 客户端驱动模拟器 |

### 训练与仿真

| 仓库 | 星 | 这是什么 |
|---|---|---|
| [Vottivott/microduck-playground](https://github.com/Vottivott/microduck-playground) | 14 | 可复现的 RL 实验、策略、仿真资产 |
| [kabilankb/isaaclab-microduck](https://github.com/kabilankb/isaaclab-microduck) | 6 | Isaac Lab 3.0 / Newton MJWarp 环境 |
| [Macmachi/microduck-rl-genesis](https://github.com/Macmachi/microduck-rl-genesis) | 2 | Genesis 移植版，**在 AMD 显卡上训** |
| [AlexBodner/microduck-tracking](https://github.com/AlexBodner/microduck-tracking) | 12 | 多目标跟踪 |

### 复刻与硬件

| 仓库 | 星 | 这是什么 |
|---|---|---|
| **本仓库** | 414 | 机械装配图 + CAD 装配体 + 打印件 + 完整电控逆向 |
| [IronSpiderMan/MicroDuckModels](https://github.com/IronSpiderMan/MicroDuckModels) | 30 | **中文**。Three.js 网页 3D 预览器，按运动学层级交互查看 |
| [ScrapMeta/microduck-diy](https://github.com/ScrapMeta/microduck-diy) | 16 | **中文**。「一个月手搓挑战」记录 |
| [SaberOnGo/open-microduck](https://github.com/SaberOnGo/open-microduck) | 7 | 中英双语硬件文档（**目前只有文档，没有 PCB 文件**） |
| [boris721/microduck-3d](https://github.com/boris721/microduck-3d) | 6 | 从上游提取的 STL + MJCF |
| [Rhoban/microban](https://github.com/Rhoban/microban) | — | ⭐ **不是 Microduck，但用同一块 HAT**。19×XL330 + Pi Zero 2W 双足，**有完整公开 BOM 和装配指南**（约 $567），采购时值得对照 |

### 历史线索

| 仓库 | 说明 |
|---|---|
| [TommyZihao/microduck_runtime](https://github.com/TommyZihao/microduck_runtime) | **原型机运行时的公开镜像**。原仓库 `apirrone/microduck_runtime` 已私有。里面记录了一件事：**原型机用的是 BNO055 走 I²C**，不是现在的 `imu_to_dxl` 板 |

---

## 从哪开始

| 你想做什么 | 去哪 |
|---|---|
| 先感受一下 | [官方网页模拟器](https://huggingface.co/spaces/pollen-robotics/microduck-simulator)，打开就能玩 |
| 看它长什么样、怎么装 | 本仓库 [`cad/`](../cad/) 和 [`assembly-drawings/`](../assembly-drawings/) |
| 打印零件 | 本仓库 [`print/`](../print/) |
| 搞懂电控 | 本仓库 [`docs/硬件方案逆向.md`](硬件方案逆向.md) |
| 做 HAT 板 | [`elec_RPI_Robot_HAT`](https://github.com/pollen-robotics/elec_RPI_Robot_HAT) 的 `production/`，别忘了先装 `lib_KiCAD` |
| 训自己的策略 | [`microduck_rl`](https://github.com/pollen-robotics/microduck_rl)；没有 N 卡就用 [microduck-lab](https://github.com/jonathanhawkins/microduck-lab) |
| 读硬件规格 | [`microduck`](https://github.com/pollen-robotics/microduck) 源码 —— **代码即规格书** |

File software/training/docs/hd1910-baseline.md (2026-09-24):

# HD1910 M6 仿真训练基线

本基线采用 **[LuwuDynamics/xgoduck_rl](https://github.com/LuwuDynamics/xgoduck_rl)
公开的 1910 BAM M6 动力学参数**，不是本项目自行辨识的数据。
[来源记录](../src/mjlab_microduck/robot/hd1910/README.md)包含固定提交、原文件
SHA-256、配套配置和 Apache-2.0 许可证副本。感谢 LuwuDynamics、
[Pollen Robotics](https://github.com/pollen-robotics/microduck_rl) 和
[Rhoban/BAM](https://github.com/Rhoban/bam) 的开源工作。

## 已接入的内容

| 项目 | 当前配置 |
|---|---|
| 平地入口 | `Mjlab-Velocity-Flat-MicroDuck-HD1910` |
| 地形入口 | `Mjlab-Velocity-Rough-MicroDuck-HD1910` |
| 舵机参数 | LuwuDynamics 的 `1910_m6.json`，原样保留 |
| 增益 / 电压 | `kp_fw=5`，7.4–8.0 V 随机电压，压降下限 7.0 V |
| 控制延迟 | 3–6 个仿真步；当前仿真步长 5 ms，即 15–30 ms |
| 策略接口 | 50 Hz，61 维观测，14 维动作；保留原 Microduck 顺序 |
| 模型 | 本地 Microduck 几何、质量、惯量和默认站姿 |
| 日志 | 独立 `microduck_hd1910_velocity` 目录，默认 TensorBoard 本地记录 |

原 XL330 训练入口仍可用。HD1910 工厂复制机器人配置后替换执行器，不影响
其他任务。没有把 XgoDuck 的 0.8 kg 模型、编码器零位、方向或 ONNX 搬到本机。
现有 Microduck 质量惯量仍是原版仿真值，后续需要按飞特实机数据校正。

### 本地兼容修复

这里修的是仿真控制器的运行状态初始化，不是重新初始化神经网络，也没有重新
拟合舵机参数。飞特模型用 `q_target_smooth` 保存上一时刻的目标角度，以限制
目标每一步变化的幅度；计算下一步之前，这份历史必须存在。

锁定的 BAM `62bd8ce` 中，飞特控制器的 `q_target_smooth` 只在读辨识日志时创建，
mjlab 训练不走这条路径。实际 GPU 仿真在首次 reset 时复现了缺少该字段的错误。

```text
AttributeError: 'STS3215Actuator' object has no attribute 'q_target_smooth'
```

`actuator/feetech_bam.py` 补齐状态初始化，并在每个环境重置后的第一次计算时，
从该环境当前关节位置重新开始目标限速，避免前一轮历史影响新姿态。
重置某一个环境时，只清理它自己的历史；其他并行环境继续保留各自状态。
选择当前关节位置作为起点，是为了避免把上轮目标或统一的零角度带进新一轮。
这个适配不改 LuwuDynamics 参数，也不修改系统安装的 BAM。

该问题是在本项目锁定的 BAM/mjlab 组合中复现的，不据此推断对方实机运行时
存在同样问题。回归检查覆盖了首次启动、连续计算和单环境重置后的历史隔离。

## 获取代码

训练代码、模型和参数统一放在 [microduck-replica 的 software/training](../README.md)。
使用 Linux CUDA 机器或已配置 GPU 的 WSL2，在其终端执行：

```bash
git clone https://github.com/fanhao375/microduck-replica.git
cd microduck-replica/software/training
uv sync --frozen --python 3.12
```

如果已克隆或下载本仓库，直接进入 `software/training/` 即可，无需子模块或另一个训练仓库。
固定导入版本与许可证见 [UPSTREAM.md](../UPSTREAM.md)。

## 怎么运行

以下命令均在 `software/training/` 目录执行，日志默认保存在该目录下：

```bash
# 列出已注册任务
uv run --frozen list-envs

# 先做短训练，检查训练和保存流程
uv run --frozen train Mjlab-Velocity-Flat-MicroDuck-HD1910 \
  --env.scene.num-envs 64 --agent.max-iterations 5 \
  --agent.logger tensorboard --agent.run-name hd1910_m6_smoke

# 接入与回归检查（包含 GPU 实际步进）
uv run --frozen --with pytest python -m pytest -q \
  tests/test_hd1910_cfg.py tests/test_hd1910_rollout.py \
  tests/test_ground_pick_cfg.py tests/test_nan_guard.py tests/test_obs_nan_guard.py \
  tests/test_hf_source_snapshot.py
```

uv 默认在 `software/training/.venv/` 建环境。如果将源码放在 Windows 磁盘上，
可在首次 `uv sync` 前设置 `UV_PROJECT_ENVIRONMENT`，把虚拟环境放到 WSL 的 Linux
文件系统中；后续命令使用同一个环境路径。飞特版使用上面的 HD1910 任务，
[原 README](../README.upstream.md) 中的默认任务面向 XL330。

可选的 `--hf-jobs` 云端提交功能需要 Git checkout；ZIP 下载只用于本地训练。
迁移后打包以训练项目为根，不包含复刻仓库中的硬件文件、照片等其他目录。
本次只验证本地打包行为，没有提交付费云端任务。

## 验证记录

2026-09-24，迁移前在 WSL Ubuntu-22.04、Python 3.12.14、RTX 5060 Ti 上，
已完成 64 个环境、5 轮 PPO 短训练，共 7,680 个环境步，
训练日志中 `Episode_Termination/nan_state` 每轮均为 0。模型日志确认加载
`kt=0.6238`、`R=4.9102`、14 个 HD1910 执行器。

- 26 项配置、回归与 GPU 步进测试通过；包含只重置一个环境时的目标历史检查。
- 短训练检查点已通过项目的标准导出脚本生成 ONNX，观测归一化包含在图中。
- ONNX 检查及 CPU 推理通过：输入 `[1, 61]`、输出 `[1, 14]`，输出为有限值，
  关节元数据与本地 Microduck 顺序一致。
- mjlab 对宽泛的关节匹配正则发出一条匹配到 site 的提示；实际执行器数检查为
  14，没有增加 site 执行器。该正则沿用上游的 `^(?!passive_).*` 约定。
- 独立代码审查核对了 reset 顺序、目标历史隔离、原 XL330 配置隔离及来源校验，
  没有提出需要修复的正确性问题；这不代替实机一致性验证。
- 默认站姿测量：4 个环境，固定 7.4 V，无推力、无自动 reset；关节和躯干
  roll/pitch 初始扰动均为 ±0.01 rad，连续保持 3 秒。最大倾角分别为
  4.47° / 6.17° / 5.94° / 5.03°，末端躯干高度约 0.1153–0.1156 m；
  该有限样本未倒下，不表示所有电压、扰动或真实硬件均稳定。

上述测量脚本、JSON、日志与导出产物保留在迁移前本地工作区的忽略目录
`artifacts/hd1910/`，短训练检查点位于该工作区的
`logs/rsl_rl/microduck_hd1910_velocity/2026-09-24_20-40-50_hd1910_m6_smoke/`。
这些本地验证产物未随源码快照发布。短训练检查点只是接入测试产物，
尚未学会走路，不能作为实机步态使用。

### 迁入 microduck-replica 后的复验

同日在 `software/training/` 路径按锁文件新建独立环境，安装成功；上述 26 项
测试再次通过。另有 4 项离线源码打包测试通过，覆盖训练独立仓库/子目录布局、
当前未提交改动、新源码和忽略产物。迁移后的 64 环境、5 轮 PPO 短训练再次完成，
共 7,680 个环境步，5 轮 `nan_state` 均为 0；加载参数仍为 `kt=0.6238`、`R=4.9102`。
参数原文件 SHA-256 与引用来源一致。

独立审查发现的 HF Jobs 打包路径和几何许可文案问题，由第二位审查者确认后修正，
最终复核未发现新的可执行问题。该轮未重复站姿测量或 ONNX 导出，前述相关数据
属于迁移前记录。复验日志和检查点仍只保留在本地忽略目录。

## 实机到手后

先确认 15 颗舵机状态并完成逐关节零位、方向和限位，再接入主控 IMU。
记录实际 P/D、运行模式、供电和总线时序，做小幅阶跃实验对比模型。
本基线 P=5 是上游训练设定；上游 Arduino 运行时使用 P=6、D=20，不能直接
视为同一套已验证的实机参数。本次没有连接或控制实机，也没有写 EEPROM。

自行训练出的策略与采用的舵机模型是两个来源层次：只要仍使用这份 M6 参数，
发布模型或训练结果时就继续保留 LuwuDynamics 的引用。

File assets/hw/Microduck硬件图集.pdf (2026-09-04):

M I C R O D U C K 复刻 · 电控

# Microduck硬件图集

五个模块、两块自制板、一条总线。所有引脚、地址与寄存器均取自官方开源硬

件工程与运行时源码，未经实物验证。

舵机总线 · 半双工 TTL 1 Mbps | +BATT 6.6–8.2 V | +5V / +3V3 | I²C · 400 kHz | MIPI CSI | I²S 音频

总线设备

16

15 舵机 ＋ 1 块 IMU 板

控制周期

20 ms

50 Hz，一读一写

自制板

2

HAT 已开源 ／ IMU 板要自绘

策略网络

775 KiB

×9 个 ONNX

## 01 东西装在哪

最容易搞错的一条：主控不在躯干，在头里。摄像头、主控板、HAT 三者同属 MJCF 里 的 jaw_soft 刚体，摄像头距主控板中心约 13 mm，中间没有任何关节。 躯干内腔基

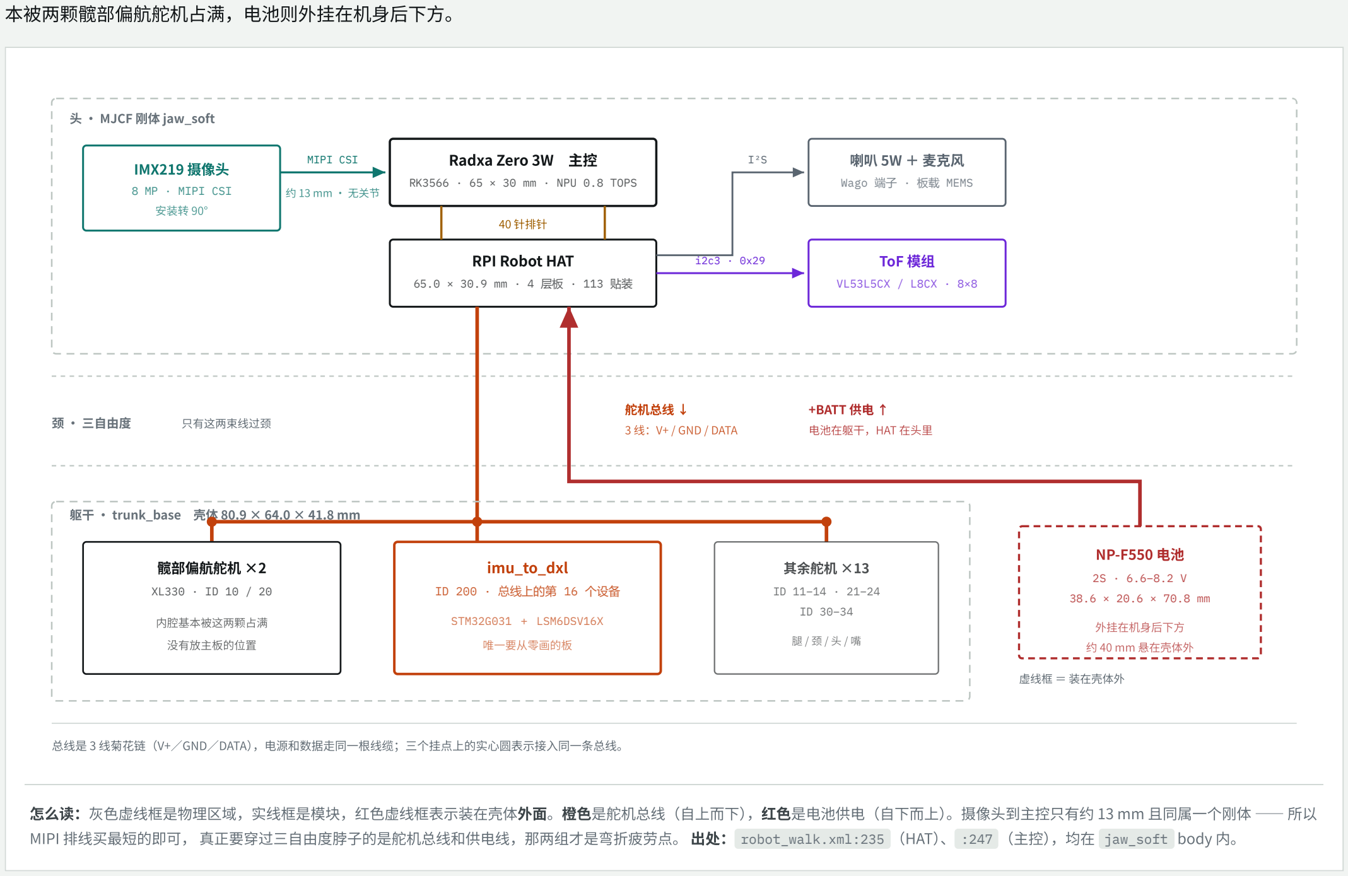
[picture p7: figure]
本被两颗髋部偏航舵机占满，电池则外挂在机身后下方。; 头 · MJCF 刚体 jaw_soft; IMX219 摄像头 8 MP · MIPI CSI; 安装转 90°; Radxa Zero 3W 主控; RK3566 · 65 × 30 mm · NPU 0.8 TOPS; RPI Robot HAT; 40 针排针; MIPI CSI; 约 13 mm · 无关节; ToF 模组; 喇叭 5W ＋ 麦克风; Wago 端子 · 板载 MEMS; I²S; 颈 · 三自由度; 舵机总线 ↓; 3 线：V+ / GND / DATA; +BATT 供电 ↑; 电池在躯干，HAT 在头里; 只有这两束线过颈; 髋部偏航舵机 ×2; 内腔基本被这两颗占满; 没有放主板的位置; imu_to_dxl; ID 200 · 总线上的第 16 个设备; STM32G031 ＋ LSM6DSV16X; 唯一要从零画的板; 其余舵机 ×13; 外挂在机身后下方; 约 40 mm 悬在壳体外; 虚线框 ＝ 装在壳体外; 总线是 3 线菊花链（V+／GND／DATA），电源和数据走同一根线缆；三个挂点上的实心圆表示接入同一条总线。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

躯干 · trunk_base 壳体 80.9 × 64.0 × 41.8 mm

MIPI 排线买最短的即可， 真正要穿过三自由度脖子的是舵机总线和供电线，那两组才是弯折疲劳点。 出处： robot_walk.xml:235 （HAT）、 :247 （主控），均在 jaw_soft body 内。

买之前先看这条

因为主控在头里、槽位只有 65 × 30 mm，任何更大的板子都塞不进去—— 立创泰

山派是 70 × 45 mm，同为 RK3566 但装不下，上面还压着一块 HAT。

## 02 电池两路走，舵机吃原压

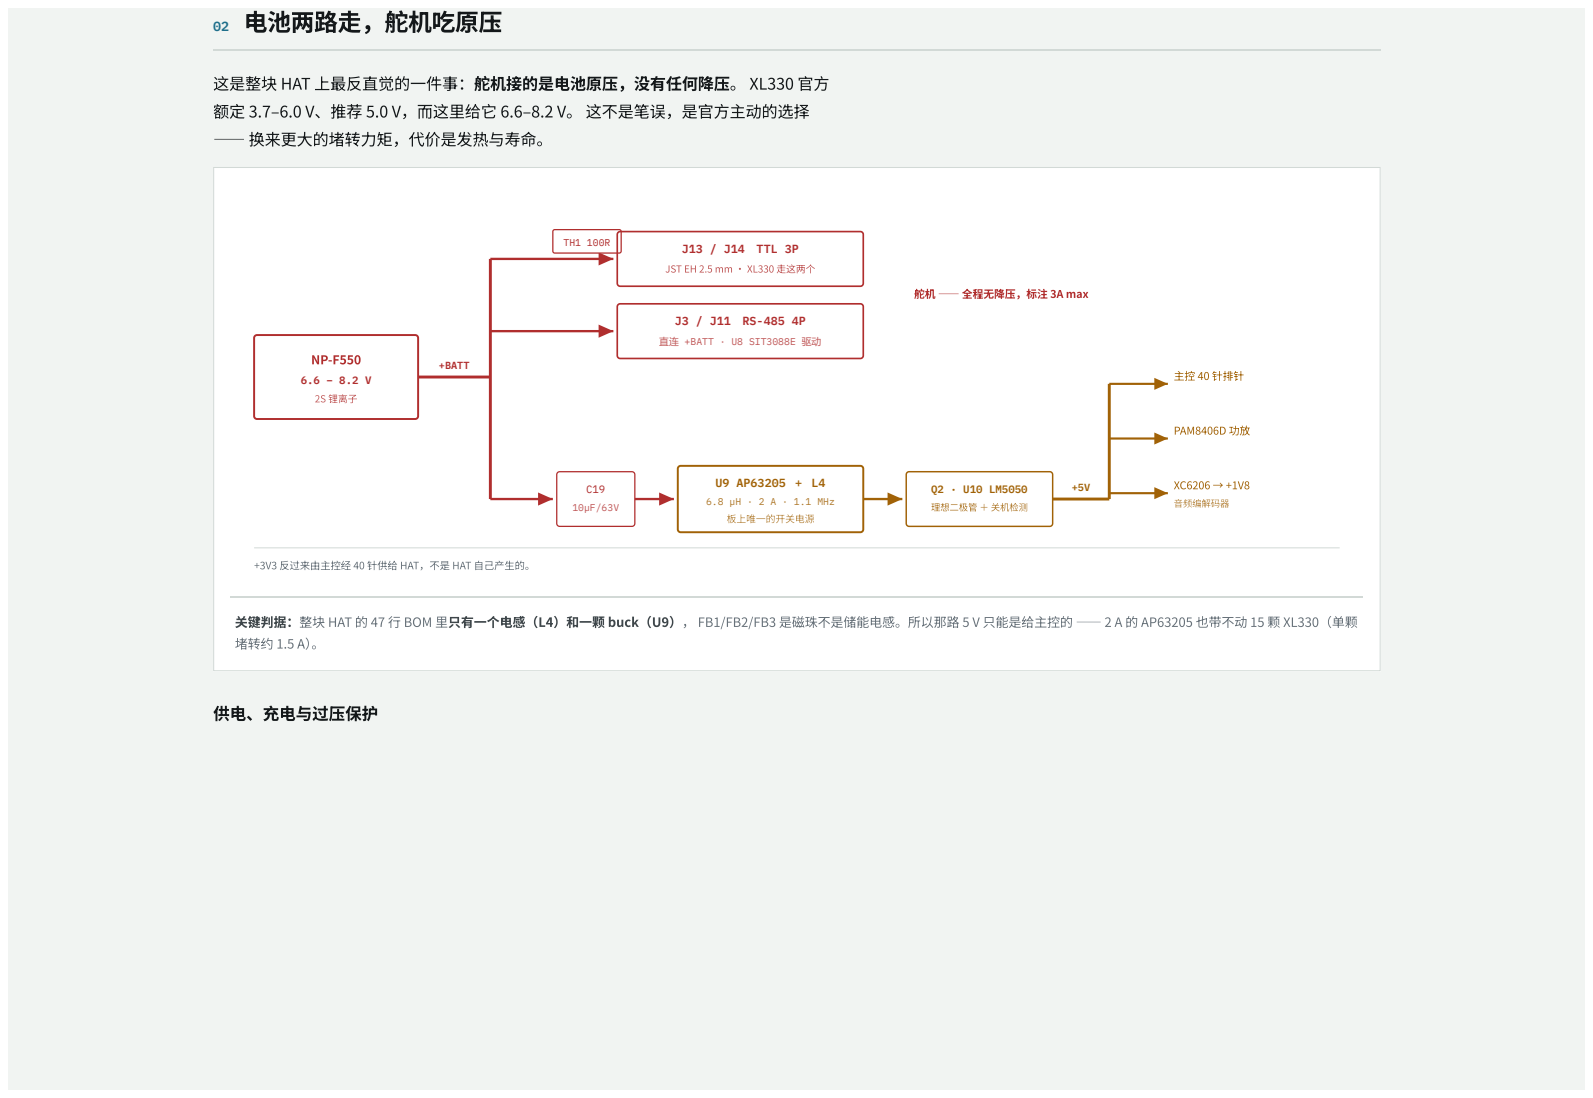
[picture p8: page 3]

这是整块 HAT 上最反直觉的一件事：舵机接的是电池原压，没有任何降压。 XL330 官方
额定 3.7–6.0 V、推荐 5.0 V，而这里给它 6.6–8.2 V。 这不是笔误，是官方主动的选择
—— 换来更大的堵转力矩，代价是发热与寿命。

JST EH 2.5 mm · XL330 走这两个

舵机——全程无降压，标注 3A max

+3V3 反过来由主控经 40 针供给 HAT，不是 HAT 自己产生的。

关键判据：整块 HAT 的 47 行 BOM 里只有一个电感（L4）和一颗 buck（U9）， FB1/FB2/FB3 是磁珠不是储能电感。所以那路 5 V 只能是给主控的—— 2 A 的 AP63205 也带不动 15 颗 XL330（单颗
堵转约 1.5 A）。

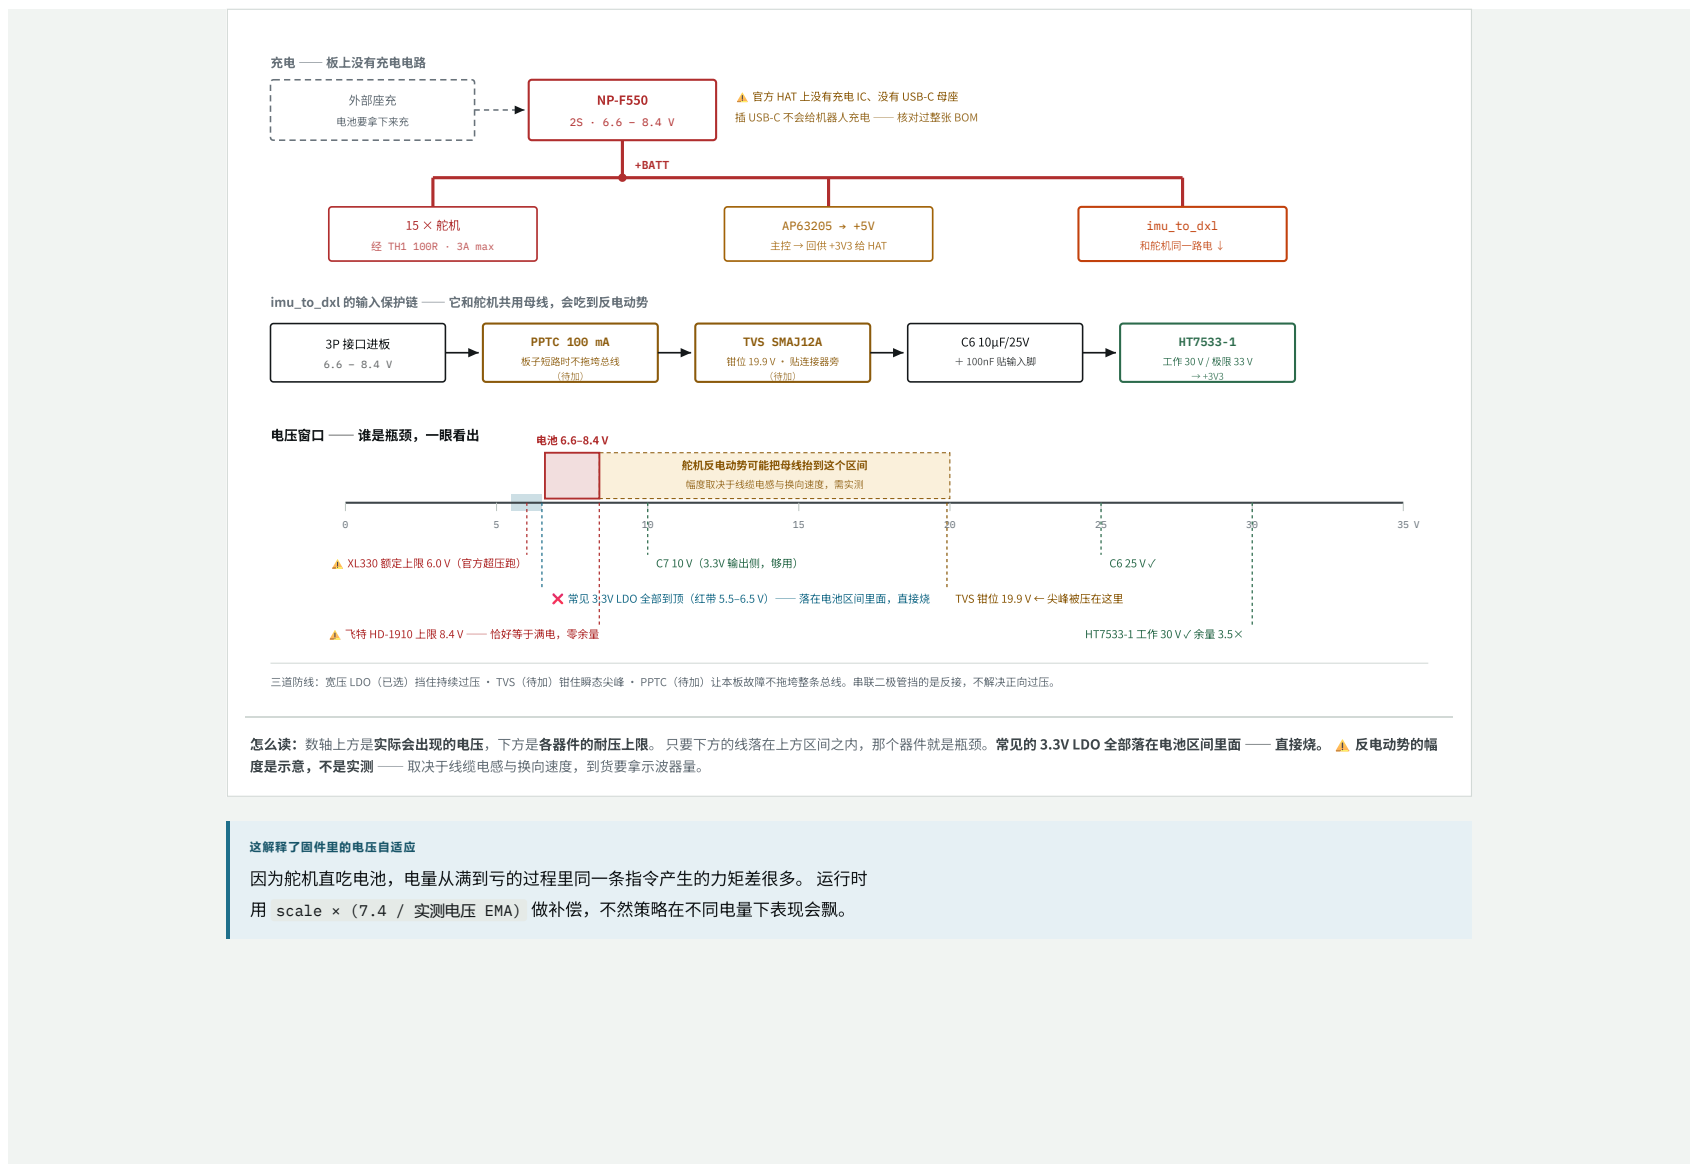
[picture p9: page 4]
充电——板上没有充电电路; 外部座充; 电池要拿下来充; +BATT; 15 × 舵机 经 TH1 100R · 3A max; imu_to_dxl; 和舵机同一路电 ↓; 3P 接口进板 6.6 – 8.4 V; PPTC 100 mA; 板子短路时不拖垮总线; TVS SMAJ12A; 钳位 19.9 V · 贴连接器旁; ＋ 100nF 贴输入脚; 舵机反电动势可能把母线抬到这个区间; 幅度取决于线缆电感与换向速度，需实测; ⚠️XL330 额定上限 6.0 V（官方超压跑）; C7 10 V（3.3V 输出侧，够用）; 这解释了固件里的电压自适应

⚠️官方 HAT 上没有充电 IC、没有 USB-C 母座
插 USB-C 不会给机器人充电—— 核对过整张 BOM

主控 → 回供 +3V3 给 HAT

imu_to_dxl 的输入保护链——它和舵机共用母线，会吃到反电动势

电压窗口——谁是瓶颈，一眼看出

❌常见 3.3V LDO 全部到顶（红带 5.5–6.5 V）—— 落在电池区间里面，直接烧

TVS 钳位 19.9 V ← 尖峰被压在这里

⚠️飞特 HD-1910 上限 8.4 V—— 恰好等于满电，零余量

三道防线：宽压 LDO（已选）挡住持续过压 · TVS（待加）钳住瞬态尖峰 · PPTC（待加）让本板故障不拖垮整条总线。串联二极管挡的是反接，不解决正向过压。

怎么读：数轴上方是实际会出现的电压，下方是各器件的耐压上限。 只要下方的线落在上方区间之内，那个器件就是瓶颈。常见的 3.3V LDO 全部落在电池区间里面—— 直接烧。⚠️反电动势的幅
度是示意，不是实测—— 取决于线缆电感与换向速度，到货要拿示波器量。

因为舵机直吃电池，电量从满到亏的过程里同一条指令产生的力矩差很多。 运行时
用 scale × (7.4 / 实测电压 EMA) 做补偿，不然策略在不同电量下表现会飘。

## 03 一条总线挂 16 个设备

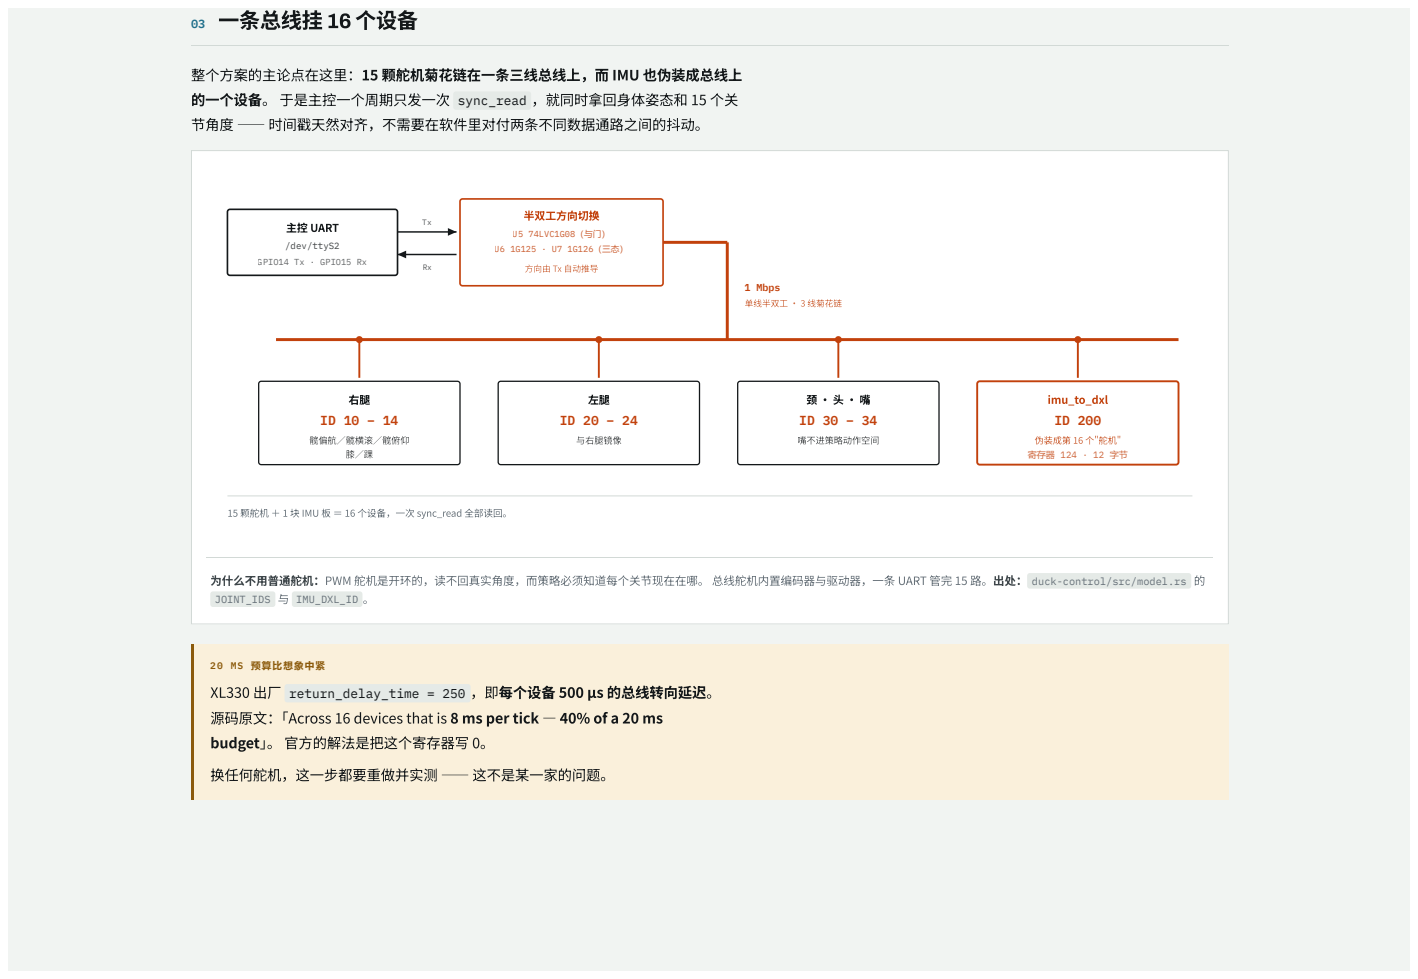
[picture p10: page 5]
主控 UART; /dev/ttyS2 GPIO14 Tx · GPIO15 Rx; 半双工方向切换; U5 74LVC1G08（与门） U6 1G125 · U7 1G126（三态）; 1 Mbps; 单线半双工 · 3 线菊花链; 与右腿镜像; 嘴不进策略动作空间; imu_to_dxl ID 200; 伪装成第 16 个"舵机" 寄存器 124 · 12 字节

整个方案的主论点在这里：15 颗舵机菊花链在一条三线总线上，而 IMU 也伪装成总线上
的一个设备。 于是主控一个周期只发一次 sync_read ，就同时拿回身体姿态和 15 个关

节角度—— 时间戳天然对齐，不需要在软件里对付两条不同数据通路之间的抖动。

方向由 Tx 自动推导

髋偏航／髋横滚／髋俯仰

15 颗舵机 ＋ 1 块 IMU 板 ＝ 16 个设备，一次 sync_read 全部读回。

为什么不用普通舵机：PWM 舵机是开环的，读不回真实角度，而策略必须知道每个关节现在在哪。 总线舵机内置编码器与驱动器，一条 UART 管完 15 路。出处： duck-control/src/model.rs 的
JOINT_IDS 与 IMU_DXL_ID 。

20 MS 预算比想象中紧
XL330 出厂 return_delay_time = 250 ，即每个设备 500 µs 的总线转向延迟。
源码原文：「Across 16 devices that is 8 ms per tick — 40% of a 20 ms
budget」。 官方的解法是把这个寄存器写 0。

换任何舵机，这一步都要重做并实测—— 这不是某一家的问题。

## 04 一个周期，20 毫秒

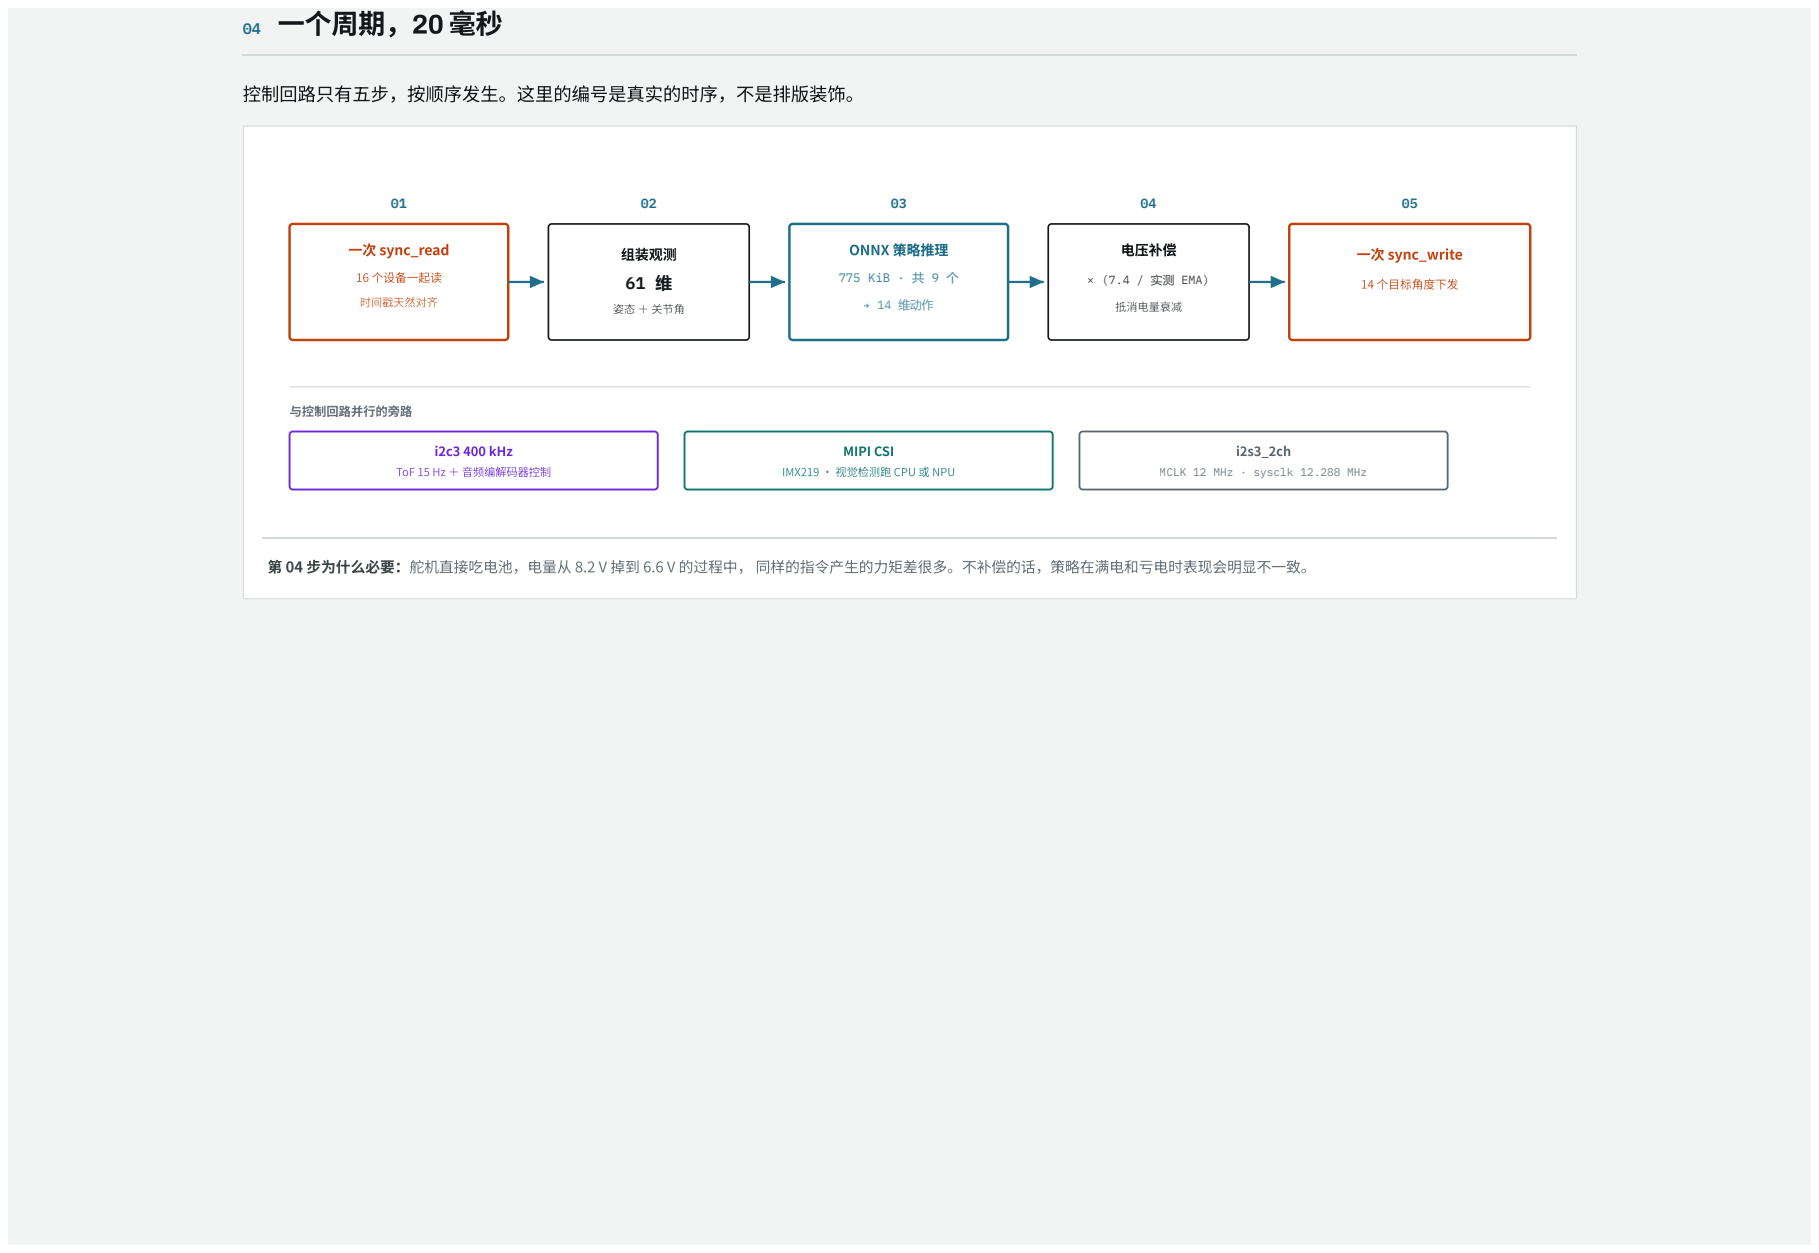
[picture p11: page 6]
一次 sync_read; 16 个设备一起读; 时间戳天然对齐; 组装观测 61 维; 姿态 ＋ 关节角; ONNX 策略推理; 775 KiB · 共 9 个; → 14 维动作; 电压补偿; × (7.4 / 实测 EMA); 抵消电量衰减; 一次 sync_write; 14 个目标角度下发; 与控制回路并行的旁路; i2c3 400 kHz; MIPI CSI

控制回路只有五步，按顺序发生。这里的编号是真实的时序，不是排版装饰。

ToF 15 Hz ＋ 音频编解码器控制

IMX219 · 视觉检测跑 CPU 或 NPU

MCLK 12 MHz · sysclk 12.288 MHz

第 04 步为什么必要：舵机直接吃电池，电量从 8.2 V 掉到 6.6 V 的过程中， 同样的指令产生的力矩差很多。不补偿的话，策略在满电和亏电时表现会明显不一致。

## 05 要自己画的那块板

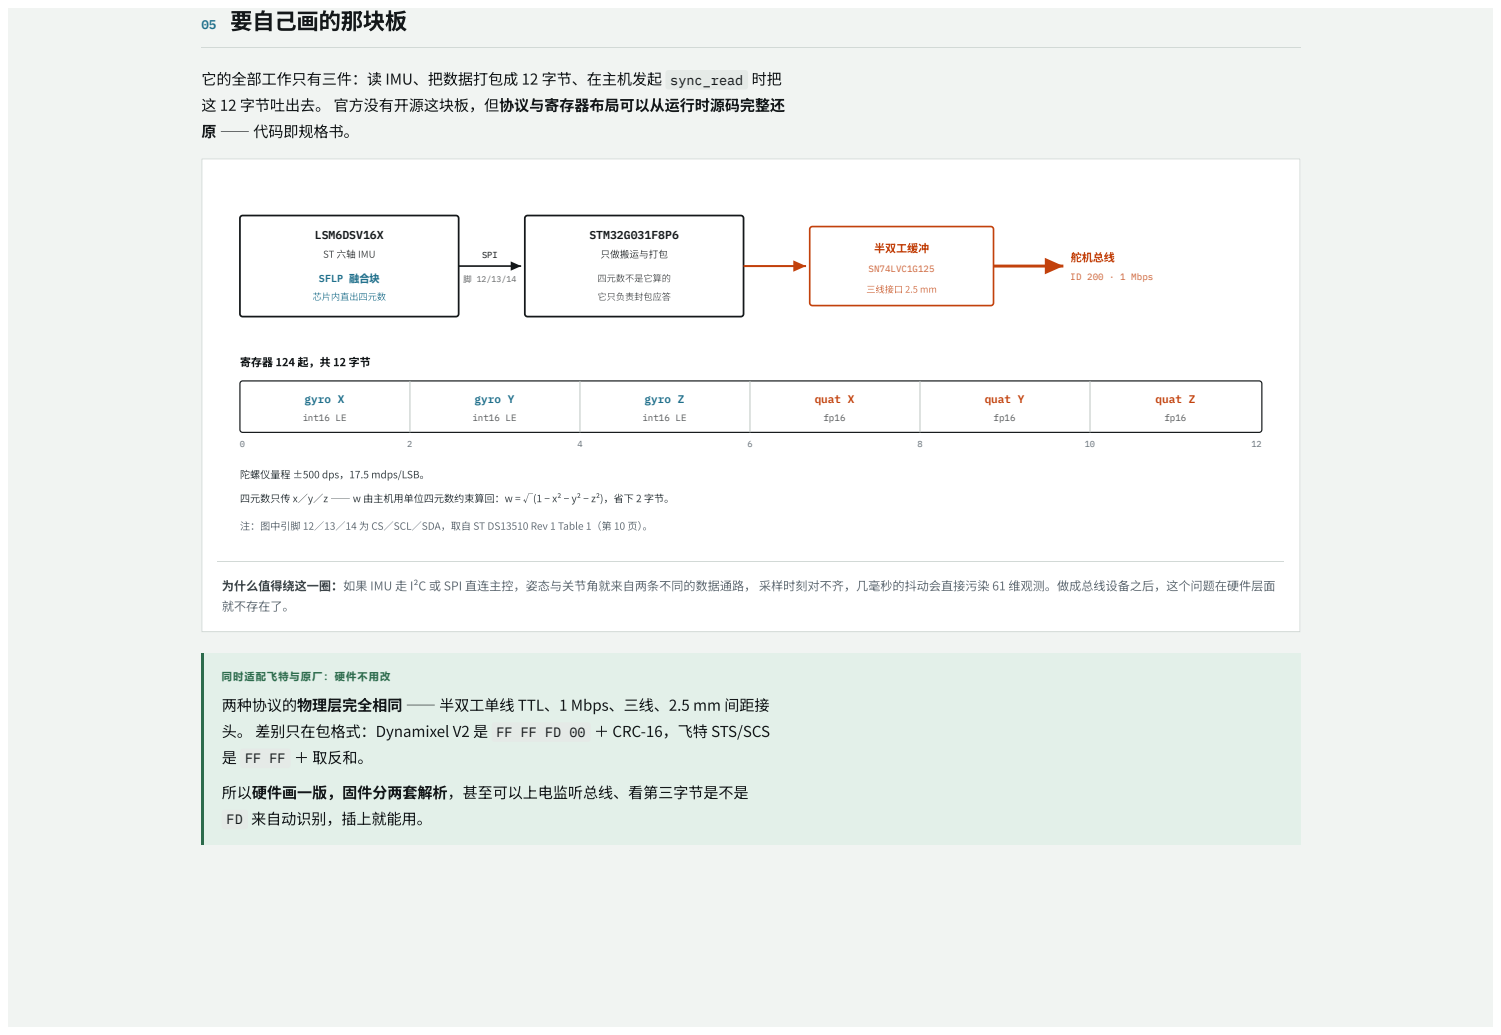
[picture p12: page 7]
LSM6DSV16X; 芯片内直出四元数; SPI; STM32G031F8P6; 只做搬运与打包; 四元数不是它算的; 它只负责封包应答; 半双工缓冲; SN74LVC1G125; 三线接口 2.5 mm; 舵机总线; ID 200 · 1 Mbps; 寄存器 124 起，共 12 字节; gyro X; gyro Y; gyro Z; quat X; quat Y; quat Z; int16 LE; 同时适配飞特与原厂：硬件不用改

它的全部工作只有三件：读 IMU、把数据打包成 12 字节、在主机发起 sync_read 时把
这 12 字节吐出去。 官方没有开源这块板，但协议与寄存器布局可以从运行时源码完整还
原—— 代码即规格书。

ST 六轴 IMU
SFLP 融合块

陀螺仪量程 ±500 dps，17.5 mdps/LSB。

四元数只传 x／y／z——w 由主机用单位四元数约束算回：w = √(1 − x² − y² − z²)，省下 2 字节。

注：图中引脚 12／13／14 为 CS／SCL／SDA，取自 ST DS13510 Rev 1 Table 1（第 10 页）。

为什么值得绕这一圈：如果 IMU 走 I²C 或 SPI 直连主控，姿态与关节角就来自两条不同的数据通路， 采样时刻对不齐，几毫秒的抖动会直接污染 61 维观测。做成总线设备之后，这个问题在硬件层面
就不存在了。

两种协议的物理层完全相同—— 半双工单线 TTL、1 Mbps、三线、2.5 mm 间距接
头。 差别只在包格式：Dynamixel V2 是 FF FF FD 00 ＋ CRC-16，飞特 STS/SCS
是 FF FF ＋ 取反和。

所以硬件画一版，固件分两套解析，甚至可以上电监听总线、看第三字节是不是
FD 来自动识别，插上就能用。

## 06 40 针占用与关键地址

引脚 / 总线 | 用途 | LINUX 设备 | 出处
GPIO14 / GPIO15 | 舵机总线 Tx / Rx | /dev/ttyS2 @ 1 Mbps | robotd.toml
GPIO02 / GPIO03 | I²C—— IMU、音频编解码器、Stemma | i2c3 @ 400 kHz | i2c3-pihat.dts
GPIO18 / 19 / 20 / 21 | 音频 PCM 时钟 / 帧同步 / 输入 / 输出 | i2s3_2ch | aic3104-i2c3.dts
GPIO06 | 关机检测 | — | HAT 原理图
GPIO22 | HAT 上 BMI088 的中断脚—— 软件不用 | — | i2c3-pihat.dts
MIPI CSI | IMX219 摄像头，安装转 90° | radxa-zero3-rpi-camera-v2 | setup-board.sh
i2c3 · 0x18 | 音频编解码器 TLV320AIC3104 | — | i2c3-pihat.dts
i2c3 · 0x29 / 0x52 | ToF，两个地址都试 | — | tof/src/main.rs
i2c3 · 0x19 / 0x68 | BMI088—— 贴了片但软件标注 dormant | — | i2c3-pihat.dts
总线 ID 200 | imu_to_dxl，寄存器 124，长 12 字节 | — | duck-control/model.rs

这张表就是核对清单

Microduck 的软件是开源的，硬件上每一个地址都能在代码里找到对应。 对不上，

就是有一边错了—— 这是复刻时最省事的验证手段。

### 07 两条路线：原厂 XL330 与飞特 STS

「把 IMU 做成总线上的第 16 个设备」这个架构，在飞特上同样成立—— 因为飞特 STS/SCS 有自己的批量读指令 SYNC READ （ 0x82 ）， 用法与 Dynamixel 完全一致。

而且两边的应答机制是一样的。Protocol V2 确实有个能把所有应答拼成一个包的 fast sync read （ 0x8A ），但官方运行时没有用它—— 全库检索 fast_sync_read / 0x8A 零命中， duck-control/src/bus.rs:236 调的是普通的

sync_read_raw_data 。 这也和源码里「500 µs per device × 16 devices ＝ 8 ms」自

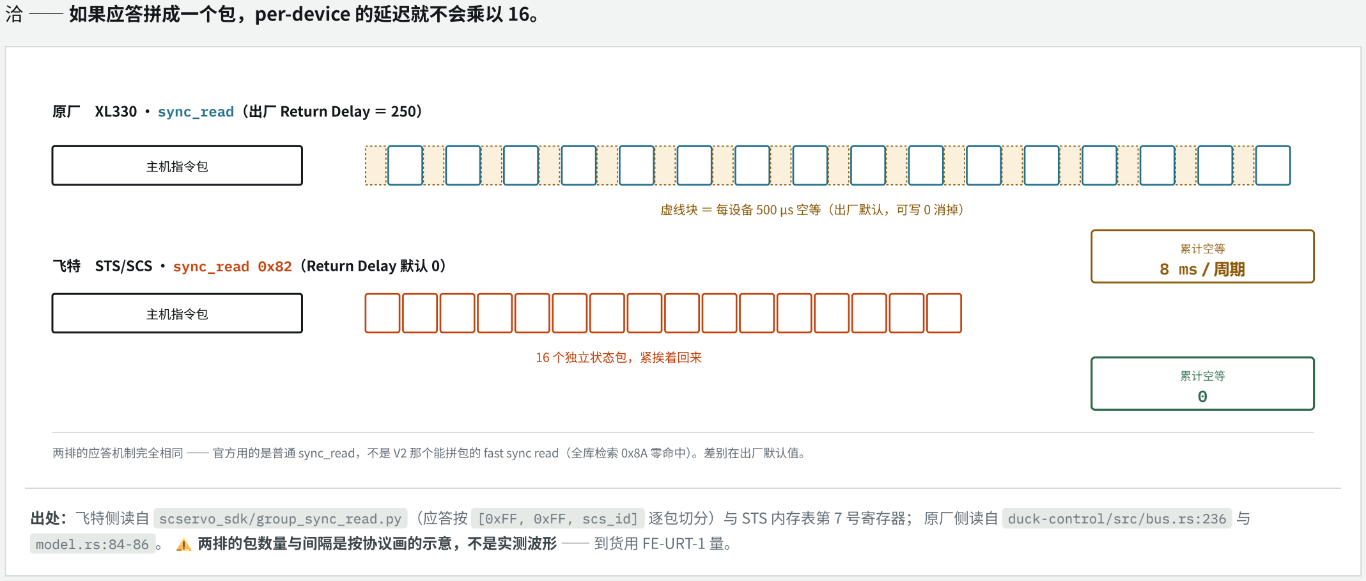
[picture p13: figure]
洽—— 如果应答拼成一个包，per-device 的延迟就不会乘以 16。; 主机指令包; 虚线块 ＝ 每设备 500 µs 空等（出厂默认，可写 0 消掉）; 累计空等; 累计空等 0; 16 个独立状态包，紧挨着回来; model.rs:84-86 。⚠️两排的包数量与间隔是按协议画的示意，不是实测波形—— 到货用 FE-URT-1 量。

原厂 XL330 · sync_read（出厂 Return Delay ＝ 250）

飞特 STS/SCS · sync_read 0x82（Return Delay 默认 0） | 8 ms／周期

两排的应答机制完全相同—— 官方用的是普通 sync_read，不是 V2 那个能拼包的 fast sync read（全库检索 0x8A 零命中）。差别在出厂默认值。

出处：飞特侧读自 scservo_sdk/group_sync_read.py （应答按 [0xFF, 0xFF, scs_id] 逐包切分）与 STS 内存表第 7 号寄存器； 原厂侧读自 duck-control/src/bus.rs:236 与

意外发现：起点其实是飞特占优

STS 内存表第 7 (0x07) 号寄存器 Return Delay Time：默认值 0， 且备注写着

"Not functional on STS"。

而 XL330 出厂是 250 ，即 500 µs／设备—— 官方源码原文： 「Across 16

devices that is 8 ms per tick — 40% of a 20 ms budget」， 必须手动写 0 才能消

掉。

既然两边的应答机制相同，这就成了出厂状态下唯一的实质差别—— 而且是飞特占

优。 当然 XL330 那边写个 0 就抹平了，所以这不是「飞特更快」，是「飞特少一个

坑」。

协议差异一览

项 | DYNAMIXEL V2 · XL330 | 飞特 STS/SCS
物理层 | 完全相同—— 半双工单线 TTL、3 线（V+／GND／DATA）、1 Mbps
接头间距 | JST EH 2.5 mm | 5264，同为 2.5 mm
包头 | FF FF FD 00 | FF FF
校验 | CRC-16 | ~sum（取反和）
批量读 | sync read（官方实际用的） 另有 fast sync read 0x8A，未被使用 | sync read 0x82
应答方式 | 相同—— 每设备一个独立状态包
总线转向／周期 | 17 ⚠️ | 17 ⚠️

⚠️转向次数是协议推论（1 条指令 ＋ 16 个应答），非实测

出厂应答延时 | 250 ＝ 500 µs／设备，须写 0 | 默认 0，且 STS 上不起作用
ID 范围 | 0 – 252 | 0 – 253（寄存器 5）
波特率设定 | 寄存器 baud_rate = 3 | 寄存器 6， 0 = 1M

飞特侧还有一个可优化的寄存器

STS 内存表第 8 (0x08) 号 Response Level，默认 1—— 「所有命令都应答」。

改成 0 之后只有 read 与 ping 才回包， 普通写指令不再占用总线时间。

这与官方对 XL330 把 return_delay_time 写 0 是同一类动作： 出厂默认值是给

通用场景的，高频控制回路要自己调。

换成飞特，各模块受什么影响

模块 | 影响 | 说明
主控 | 不变 | 与舵机协议无关
摄像头 / ToF | 不变 | 走各自独立的接口
HAT | 完全不用改 | 飞特与 XL330 物理层完全相同—— 三线半双工 TTL、1 Mbps、2.5 mm 间距接头。HAT 上的 J13／J14 是 TTL 3P 口，直接插飞特舵机即可， 一根线都不用动
imu_to_dxl | 硬件架构不 变 | 物理层相同，所以硬件画一版即可；固件里按包头第三字节是不是 FD 自动识别协议，两套解析分支。连接器统一到 2.5 mm 间距，两边通用
策略 | 大概率要重
| 训

舵机换了意味着力矩曲线与质量都变了，官方九个 ONNX 不能直接套用。这是整条路线上最大的一笔工作量，与协议无关

另一个问题：这块 HAT 到底要不要做

这与用哪家舵机无关，是纯成本判断。HAT 是 4 层板加贴片，打样几百元起且有起

订量， 而板上约一半电路是音频（编解码器、功放、板载麦克风、喇叭端子）。

如果你不做语音功能，那半块板就白打了—— 此时一块二十几元的总线转接板加一

个降压模块， 就顶掉了「舵机总线」和「配电」这两件真正必需的功能，ToF 直接

挂 i2c3。 代价是失去板载音频与 Pi HAT+ 身份识别。

画板子之前先做这件事

上面的转向次数是协议事实，但换算成毫秒是估算。真实数字取决于三态缓冲切换

速度、 包间隙与实际读取的寄存器长度—— 只有拿实物测过才知道。

舵机到货第一件事：接上调试板，用两种读法各跑一遍，量出 16 个设备一轮的实际

耗时。 这个数不出来，板子上的架构决策就是空转。

基于官方公开的 MJCF 模型、STL 网格、开源硬件工程（elec_RPI_Robot_HAT，Apache-2.0） 与运行时源码推导，未经实物验证。图中所有引脚、地址、寄存器与器件位号均可在上述来源中复核。

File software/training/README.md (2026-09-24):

# Microduck HD1910 仿真训练

飞特 HD-1910 的训练代码、模型、参数、依赖锁文件和测试统一维护在本目录。
下载或克隆 `microduck-replica` 即可取得完整工程，无需再拉训练分支或初始化子模块。

采用 **[LuwuDynamics 公开的 1910 BAM M6 参数](src/mjlab_microduck/robot/hd1910/README.md)**，
训练框架与 Microduck 几何来自 [Pollen Robotics](https://github.com/pollen-robotics/microduck_rl)，
执行器模型来自 [Rhoban/BAM](https://github.com/Rhoban/bam)。参数不是本项目自行辨识的结果。
本项目补充 HD1910 任务配置、飞特控制器状态初始化适配及回归检查。

## 快速开始

使用有 NVIDIA CUDA GPU 的 Linux，或已配置 GPU 的 WSL2；需要 Git 和 [uv](https://docs.astral.sh/uv/)。
在 Linux / WSL 终端执行：

```bash
git clone https://github.com/fanhao375/microduck-replica.git
cd microduck-replica/software/training
uv sync --frozen --python 3.12

# 先用 64 个环境、5 轮迭代检查训练链路
uv run --frozen train Mjlab-Velocity-Flat-MicroDuck-HD1910 \
  --env.scene.num-envs 64 --agent.max-iterations 5 \
  --agent.logger tensorboard
```

如果已经下载本仓库，直接进入 `software/training/` 安装和运行即可。
可选的 HF Jobs 云端提交功能需要通过 Git 克隆，以便按 Git 忽略规则打包源码；
直接下载 ZIP 适用于上述本地训练。
日志与检查点保存在本目录的 `logs/rsl_rl/microduck_hd1910_velocity/`，不随源码发布。
5 轮短训练用于检查加载、步进和保存流程，尚不足以学会走路。

| 入口 | 用途 |
|---|---|
| `Mjlab-Velocity-Flat-MicroDuck-HD1910` | HD1910 平地速度任务 |
| `Mjlab-Velocity-Rough-MicroDuck-HD1910` | HD1910 地形速度任务 |

当前是仿真接入基线，尚无本机实测通过的走路策略。质量惯量仍沿用原版 Microduck
仿真值；后续需要结合飞特实机校正，并核对零位、方向、限位、供电、IMU 和通信时序。

## 说明与测试

- [使用说明、验证记录与初始化问题解释](docs/hd1910-baseline.md)：缺失的是飞特控制器的目标角度历史，修复不改变借用的 M6 参数。
- [来源、固定版本与许可证范围](UPSTREAM.md)。
- [原训练项目 README](README.upstream.md)：保留上游任务和工具说明，其中默认任务面向 XL330；飞特版使用上表的 HD1910 入口。

在本目录运行接入与回归检查（包含 GPU 步进）：

```bash
uv run --frozen --with pytest python -m pytest -q \
  tests/test_hd1910_cfg.py tests/test_hd1910_rollout.py \
  tests/test_ground_pick_cfg.py tests/test_nan_guard.py tests/test_obs_nan_guard.py \
  tests/test_hf_source_snapshot.py
```

策略导出沿用 `scripts/export.py`，把观测归一化包含在 ONNX 中。短训练检查点只用于
验证流程，不作为实机步态发布。

## 许可

本训练目录的代码、配置、参数和文档采用 [Apache-2.0](LICENSE)，保留第三方署名。
**3D 模型与网格遵循上游 CC BY-NC-SA 声明**，不因并入本仓库而改为 Apache-2.0；
详见 [UPSTREAM.md](UPSTREAM.md) 与根目录 [NOTICE.md](../../NOTICE.md)。

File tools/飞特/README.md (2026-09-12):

# 飞特舵机调试软件

配 ID、改参数、拉滑杆看舵机转 —— **就这两个文件，解压就能用，Windows。**

| 文件 | 干什么 | 版本 | 大小 |
|---|---|---|---|
| `FD1.9.8.5(250729).7z` | **FD 调试软件**。配 ID、开过流过压保护、拉滑杆测舵机 | 1.9.8.5（2025-07-29），中英文可切换 | 167 KB |
| `CH340_URT.rar` | **USB 转串口驱动**。**URT-2 用不上** —— 它是 CH343，Win10/11 自带驱动，插上就有 COM 口（实测 2026-09-12）。老款 URT-1 是 CH340，不认串口才装这个 | — | 224 KB |

## 装法

```
1  插 URT-2 → 设备管理器「端口」里出现 USB-Enhanced-SERIAL CH343 (COMx)，记下号
   没出现才装 CH340_URT.rar（那是给老款 URT-1 的）
2  解压 FD1.9.8.5(250729).7z → 直接运行，不用安装
3  FD 里选那个 COM 口 → 波特率 1000000 → 点「打开」→ 点「搜索」
```

搜到舵机就通了。**怎么飞线、怎么供电、配 ID、改哪些参数、ID 对照表** —— 全在 [调试记录 · 舵机配置](../../调试记录.md#舵机配置--拿到货一步一步做)，一步一步。

## 来源与校验

从飞特官方 Gitee 仓库 [gitee.com/ftservo/fddebug](https://gitee.com/ftservo/fddebug) master 分支原样复制（2026-09-11），**MIT 许可**（`LICENSE` 同目录）。

```
sha256
FD1.9.8.5(250729).7z   33b92ac03ff048238bb6455a96aec98e97f6c87a97903ac197406f6d937c7734
CH340_URT.rar          546aaf96a54647f7a3ddd7e21389d64be2d198926c6058d8b19ee90e9eea4e17
```

怀疑文件坏了就 `sha256sum` 一下对这两行。

**为什么放进仓库**：Gitee 有时要登录才能下、有时改目录结构，clone 下来的人不该再去找。MIT 允许原样分发。
**要更新**：去上面那个仓库拿新版，换文件、改这里的版本号和哈希、改 [NOTICE](../../NOTICE.md) 里的版本。

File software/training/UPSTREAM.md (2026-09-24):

# 训练工程来源与维护位置

本目录是普通源码目录，随 `microduck-replica` 一起克隆和下载，不是 Git 子模块。
后续 HD1910 训练工作维护在这里；原 `fanhao375/microduck_rl` 的 HD1910 分支保留作历史来源。

## 导入版本

2026-09-24 从以下固定版本导入已跟踪的完整源码快照：

- 来源：[fanhao375/microduck_rl @ d9e1926](https://github.com/fanhao375/microduck_rl/tree/d9e1926c5220a0eb79fa5aab9df7b336f8e9a226)
- 完整提交：`d9e1926c5220a0eb79fa5aab9df7b336f8e9a226`
- Pollen Robotics 上游基线：`d424a0c899f6b33cbd3daeb279913134349c0b63`；在其上增加 HD1910 任务、M6 参数引用、初始化适配和测试。
- 导入方式：该提交的 `git archive` 源码快照；不包含 `.git`、虚拟环境、训练日志或检查点。
- 原 README 原样保存为 [README.upstream.md](README.upstream.md)。迁移调整本目录的说明与入口链接，
  并修正 HF Jobs 的打包根目录，让归档仅包含训练工程；补充本地打包回归测试。
  训练/执行器逻辑、依赖锁文件、配置、原有测试和几何资产保持该版本内容。

这份快照中的 Microduck 几何、质量惯量和关节约定来自训练项目，不代表飞特复刻实机已完成测量。

## 作者与许可证

| 内容 | 来源 | 许可 |
|---|---|---|
| 训练框架、原有任务、工具及文档 | [Pollen Robotics / microduck_rl](https://github.com/pollen-robotics/microduck_rl) | [Apache-2.0](LICENSE) |
| Microduck 3D 模型与网格 | 同上 | 上游 README 的 CC BY-SA-NC 声明；本仓按 CC BY-NC-SA 4.0 保留署名、非商用与相同方式共享条件，见 [NOTICE](../../NOTICE.md#许可证名称说明) |
| `1910_m6.json` 舵机动力学参数与配套配置参考 | [LuwuDynamics / xgoduck_rl](https://github.com/LuwuDynamics/xgoduck_rl) | [Apache-2.0 副本](src/mjlab_microduck/robot/hd1910/LICENSE) |
| BAM 执行器模型与辨识库（通过依赖安装） | [Rhoban / BAM](https://github.com/Rhoban/bam) | Apache-2.0；锁文件固定 `62bd8ce12154340be97e06f7f41a0ca8f116d967` |
| HD1910 任务、状态初始化适配、相应测试与本目录新增文档 | 本复刻项目 | Apache-2.0 |

根目录对本项目其他文档的 CC 许可不覆盖本训练目录的 Apache 文档；3D 模型许可单独保留。
依赖库继续遵循各自许可证。

## 参数原始出处

- LuwuDynamics 固定提交：`326d77a1122870bdefa2c36403937502c958e69c`
- 原路径：`src/mjlab_microduck/robot/xgoduck/params/1910_m6.json`
- 本目录路径：[`src/mjlab_microduck/robot/hd1910/1910_m6.json`](src/mjlab_microduck/robot/hd1910/1910_m6.json)
- 原文件 SHA-256：`ef2d51adfb1cc0831b9b02ca19aa9176fceecdf725148d084378d7d9a64afceb`

参数按原文件保留，不是本项目自行辨识的结果。详细引用和配置边界见
[参数来源](src/mjlab_microduck/robot/hd1910/README.md)。以后基于这些参数训练自己的策略，仍保留参数作者署名。

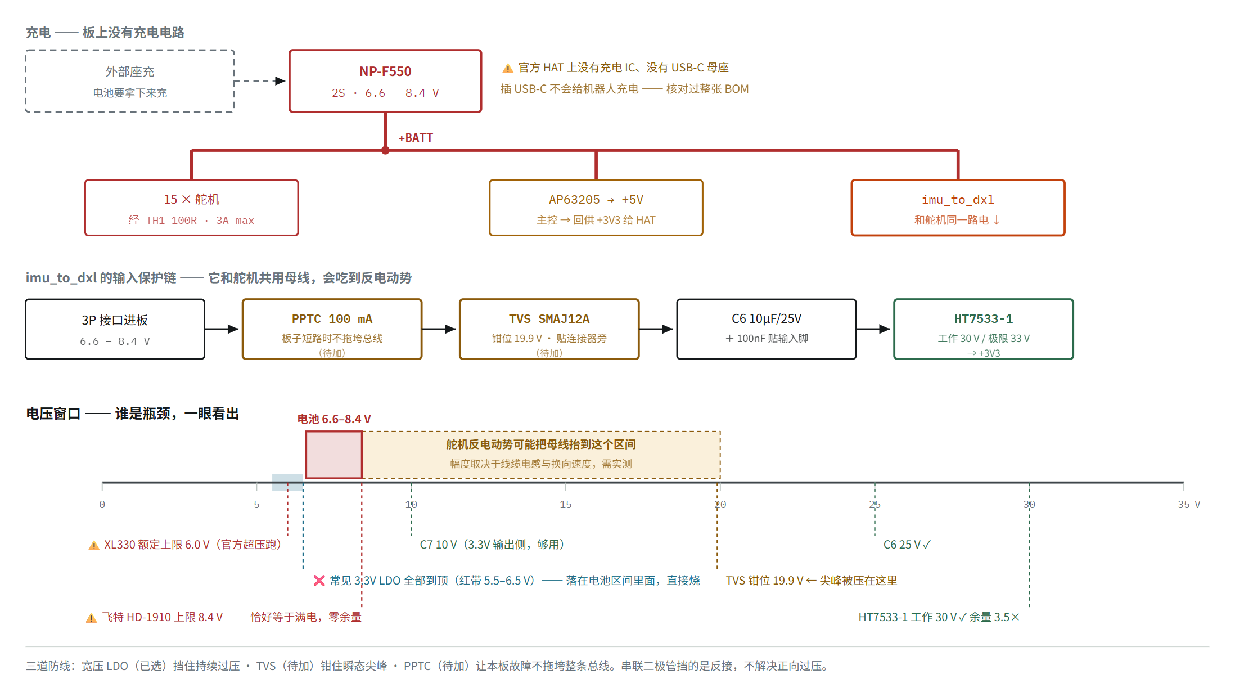
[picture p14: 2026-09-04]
assets/hw/02b-供电与保护.png

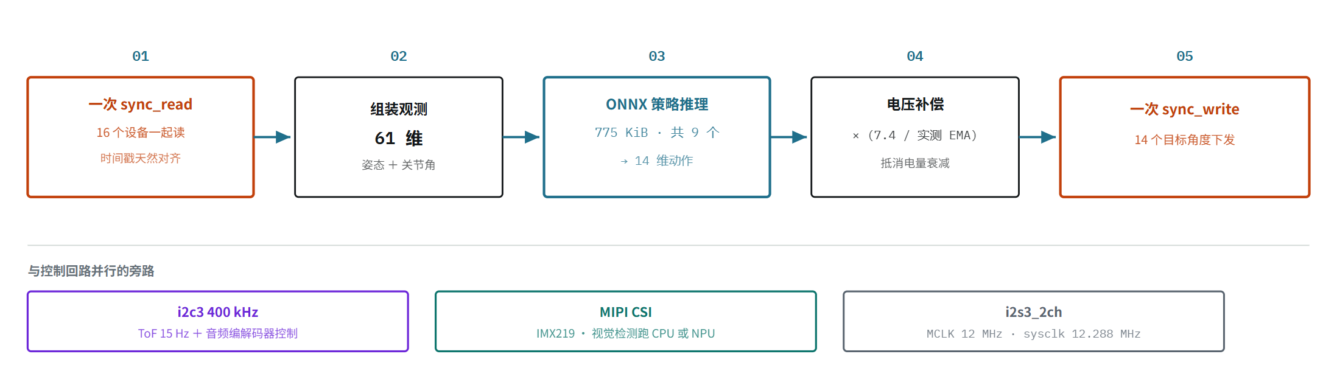
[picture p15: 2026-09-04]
assets/hw/04-控制周期.png

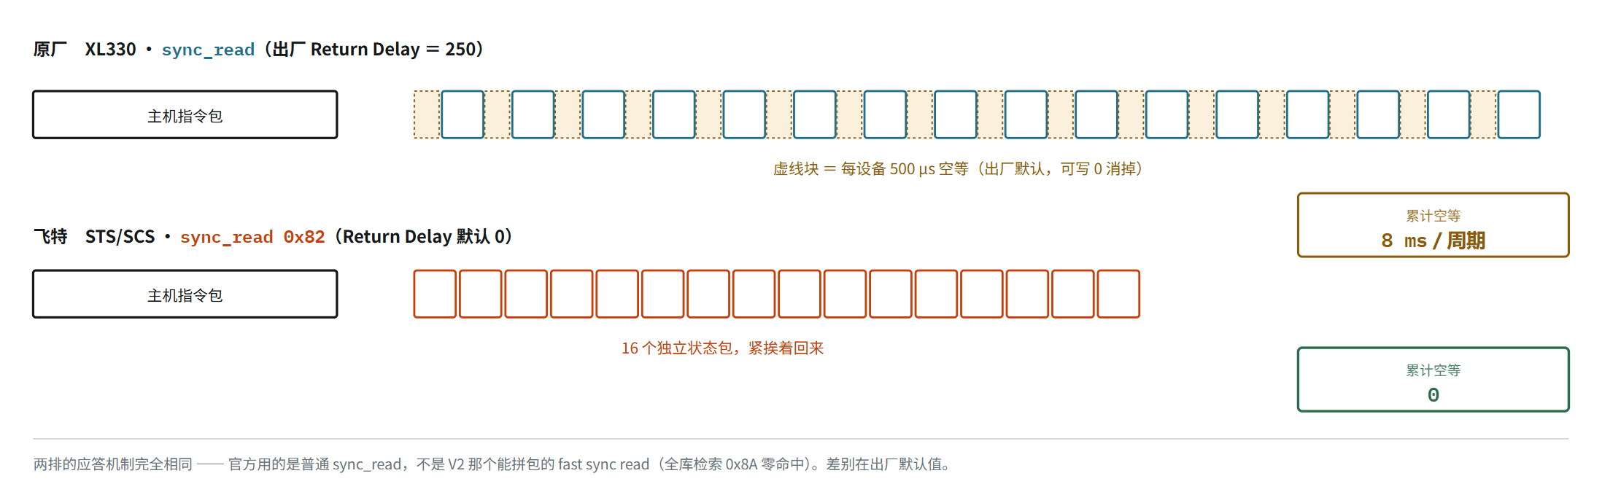
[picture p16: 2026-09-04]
assets/hw/06-总线时序对比.png

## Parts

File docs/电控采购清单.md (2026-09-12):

# 电控采购清单（国内 / 淘宝）

> **快照时间：2026-09-04。** 价格与销量会变，链接可能失效，下单前自己核价。
> 机械件（轴承 / 紧固件 / 耗材）见 [机械采购清单](机械采购清单.md)。
>
> 本清单不含推荐背书，只是搜索结果记录。店铺信息（销量、年限）为抓取时的显示值。

---

## 先搞清楚：板子都装在哪

这一条直接影响你买什么规格的线，**很容易搞错**：

```
头（MJCF 里的 jaw_soft 刚体）
 ├── Raspberry Pi 形态主控板     ← 主控在头里，不在躯干
 ├── RPI Robot HAT               ← 叠在主控上方 7.3 mm
 ├── IMX219 摄像头 + M12 镜头     ← 距主控板中心约 13 mm，同一刚体，中间没有关节
 └── 喇叭

躯干（trunk_base）
 ├── 两颗 hip_yaw XL330          ← 内腔基本被这两颗占满
 ├── trunk_base 底板
 └── NP-F 电池 —— 外挂在机身后下方，71 mm 长有约 40 mm 悬在壳体外，
      由两片 power_support 从外面夹住

穿过三自由度脖子的是：舵机总线 + 从电池上来的 +BATT 供电线
```

**证据**：`robot_walk.xml:235` `mesh="elec_rpi_robot_hat_pcb"`、`:247` `mesh="pcb__raspberry_pi_zero_2_w"`
两个 geom 都在 `jaw_soft` body 内；两块 65×30 板 X/Y 完全对齐、Z 间距 7.3 mm，是标准的 Pi + HAT 叠层。

> ⚠️ **所以 MIPI 排线不过脖子，买最短的就够。** 真正的线束疲劳风险在**舵机总线和电源线过颈**上
> —— 那是承流线，风险比信号排线更值得重视。而官方**没有公开任何走线资料**。

---

## 一、主控 · Radxa Zero 3W

### 该买哪个配置

**结论：2G / 16G eMMC。** 推算依据：

**存储侧**

| 项 | 体积 | 依据 |
|---|---|---|
| Armbian headless rootfs | ~2 GB | `deploy/README.md:144` 确认是 headless 镜像；**2 GB 是外部经验值，仓库无依据** |
| **ONNX Runtime** | **~20 MB** | `docs/design/robotd-design.md:420` 原文：「ONNX Runtime is a board prerequisite … **~20 MB** in every artifact would enlarge every update for nothing」——**板级预装，不在 release 包里** |
| **GStreamer 栈**（`mediad` 用） | **~100 MB** | `docs/design/updater-design.md:901`「the GStreamer stack for `mediad`, which is **around 100 MB of apt**」 |
| RKNN 运行时 `.so` | 未知 | 仓库无依据，不编数字 |
| daemon 制品 + 保留的一份旧版本 | 量级 10¹ MB | `Cargo.toml:79`「**model artifacts will dwarf a few MB of binary**」；`keep_previous = 1` |
| **9 个运动策略 ONNX** —— 每个 **793,685 B ≈ 775 KiB** | **7 MB** | 实测。`alpha_stand` / `alpha_walking` / `alpha_sitstand` / `alpha_ground_pick` / `ball_kick_left` / `ball_kick_right` / `roller` / `roller_crouch` / `roulade` |
| `duck_detect.onnx` | 10.0 MB | 实测 10,477,940 B |
| `pet_detect.onnx` | 19 KB | 实测 20,201 B |
| journald 上限 `SystemMaxUse=200M` | **默认配置下不占盘** | `/var/log` 是 zram 设备（`deploy/README.md:14/402/437`）。但 README:454 给了退路：关掉 `armbian-zram-config` 后日志就落到 eMMC |
| **合计** | **≈ 3 – 4 GB** | |

→ **8 GB eMMC 够，16 GB 舒服，64 GB 毫无意义。**

> 💡 **升级机制不需要双份 rootfs。** 但**别叫它 A/B** —— 上游 `docs/design/updater-design.md:46`
> 专门澄清过：「Update granularity | **Application-level (not A/B image)** | Only daemon + model
> change; OS is static. A/B (RAUC/Mender) would be over-engineering.」
> 实际是**版本目录 + `current` 符号链接原子切换（`rename(2)`）+ 健康门禁 + 回滚**，
> `keep_previous = 1` 只多留一份旧 daemon。（`updater.toml` 的 `tag_prefix` 实际值是 `daemon-v`。）

**内存侧**

| 项 | 占用 |
|---|---|
| Armbian headless | ~250 MB（外部经验值） |
| robotd + ONNX Runtime + RKNN | 小 —— 策略模型只有 775 KiB/个 |
| 摄像头 / GStreamer 缓冲 + `duck_detect` | ⚠️ **`duck_detect.onnx` 跑 CPU 不跑 NPU**（`robotd.toml:324`「a `.rknn` runs on the NPU, an `.onnx` on the CPU」；NPU 版 `.rknn` 不在仓库里）。且 **RK3566 的 NPU 与 CPU 共用 DDR，没有独立显存** |
| ⚠️ `/var/log` 的 zram 设备 —— **吃 RAM 不是盘** | 需预留 |

→ **1 GB 能跑但紧，2 GB 舒服，8 GB 纯浪费。**

> ⚠️ **官方公布的是 1 GB / 32 GB，但那不等于复刻也该买这档。**
> 官方 2026-08-27 发布页列出 **1 GB / 32 GB eMMC**（正是 Radxa Zero 3W 的一个 SKU，
> 也反向佐证了主控判断）；但 `microduck/` 源码里查不到任何板卡 SKU —— 源码本来就不体现这个。
> **按上面的体量推算，复刻建议 2G/16G**：1 GB 要和 zram 日志设备分内存，跑起来偏紧。

### 渠道 —— 国内电商价格全线虚高

官方分销商 [ALLNET China](https://shop.allnetchina.cn/products/copy-of-radxa-zero-3w) 实价（USD，约 ¥7.2/$）：

| 配置 | 价格 | 约合 |
|---|---|---|
| 1G / 无 eMMC | $18 | ¥130 |
| 1G / 8G eMMC | $22 | ¥158 |
| **2G / 16G eMMC** | **$32.90** | **¥237** ⭐ |
| 4G / 32G eMMC | $50 | ¥360 |
| 8G / 32G eMMC | $70 | ¥504 |

（带排针 +$1。ALLNET 不供 8G/64G 规格。）

国内在售：

| 店铺 | 配置 | 价格 | 链接 |
|---|---|---|---|
| findboard旗舰店 | 8G+64G「套餐6」（含摄像头/电源/32G卡/HDMI线/散热） | **¥1469** | [tmall 752703346347](https://detail.tmall.com/item.htm?id=752703346347) |
| findboard旗舰店 | 8G+64G 裸板 | ¥1149 | 同上 |
| 鹭控自动化工控 | 未注明（议价） | ¥690 | [taobao 1044607515575](https://item.taobao.com/item.htm?id=1044607515575) |

**溢价 3–6 倍。** 建议走 ALLNET China、速卖通或瑞莎官方渠道；国内也可问
[mcuzone 杭州野芯科技店](https://item.taobao.com/item.htm?id=1055301489376)（做了整套 Zero 3W 扩展板，大概率有裸板货源）。

### 套餐别买

| 配件 | 值不值 |
|---|---|
| 摄像头（瑞莎自家 IMX219，单卖 ¥129.99） | ❌ 通用 IMX219 ¥32.8 就有 |
| 32G microSD | ❌ 有 eMMC 就用不上 |
| 电源适配器 | ❌ 机器是电池供电，只台面调试用 |
| microHDMI 线 | ❌ Microduck 跑 headless |
| 散热片 | ✅ 有用，但单买 [¥19.99](https://item.taobao.com/item.htm?id=788387010174) |

---

## 二、主控备选 · 立创·泰山派（评估过，**塞不进去**）

同为 **RK3566**，国内货源稳，常被问到。**但结论是不能用。**

**实价**（点开选中「2G+16G 单主板」SKU 后的真价；列表页 ¥22 / ¥45 / ¥195 全是最低 SKU 诱导）：

| 渠道 | 配置 | 实价 | 链接 |
|---|---|---|---|
| RK开发板（9年老店） | 2G+16G 单主板 | **¥428**（+¥10 运费） | [taobao 1017038620459](https://item.taobao.com/item.htm?id=1017038620459) |
| 电子元件shop（12年老店，46付款） | 2G+16G 单板 | **¥480.8**（免运费） | [taobao 800894187326](https://item.taobao.com/item.htm?id=800894187326) |
| 立创商城官方 | 2G+16G | **¥580**（原 ¥228，DDR 涨价上调） | [item.szlcsc.com/20558171](https://item.szlcsc.com/20558171.html) |
| **对比：Radxa Zero 3W** | 2G/16G | **≈¥237** | ALLNET China |

**四条都不利：**

| | 泰山派 | Radxa Zero 3W |
|---|---|---|
| **装得下吗** | ❌ **装不下** —— 主控装在**头里**，头壳整体只有 58.8 × 91.8 × 122.7 mm，<br>主控槽在 X 方向只有 30 mm，上面还压着一块 HAT。泰山派 **70 × 45** 没有位置 | ✅ 65 × 30，就是按这个槽设计的 |
| 2G+16G 实价 | ¥428–580 | **≈¥237** |
| **Armbian 镜像** | ❌ 官方部署脚本整套基于 Radxa 的 Armbian 镜像<br>（`overlay_prefix=rk35xx`、`armbian-zram-config`、netplan、升级器），要重写 | ✅ 直接用 |
| **设备树 overlay** | ❌ 全要重写 —— 40-pin 引脚复用是**板级映射**。<br>Microduck 依赖 `/dev/ttyS2`、`i2c3 @400kHz`、`i2s3_2ch`、MIPI CSI | ✅ 现成 |
| **HAT 机械兼容** | ❌ 70×45 vs Pi Zero 65×30，排针位置对不上，**HAT 得重画** | ✅ 同为 Pi Zero 形态 |
| SoC / NPU / rknn | ✅ 同为 RK3566，内核与 NPU 工作可复用 | ✅ |
| WiFi | AP6212（WiFi4 / BT4.x） | WiFi6 / BT5.4 |

**但它的开源资料值得收着**（不用买板也能下）：完整原理图 + PCB 是**嘉立创 EDA 格式**，
同一颗 RK3566 的电源树、DDR 布线、AP6212 接法都能直接打开看 —— 画 `imu_to_dxl`
或以后重画 HAT 时是现成的高质量参考。

- [立创开源硬件平台 · 泰山派工程](https://oshwhub.com/li-chuang-kai-fa-ban/li-chuang-tai-shan-pai-kai-fa-ban)
- [资料下载中心](https://openkits-wiki.easyeda.com/zh-hans/tspi-rk3566/download-center.html)

---

## 三、摄像头 · IMX219（MIPI CSI）

摄像头与主控**同在头部、同一刚体**，`setup-board.sh:748` 用的 overlay 是
`radxa-zero3-rpi-camera-v2`，`setup-rkaiq.sh:147` `SENSOR = imx219`。

> ⚠️ **是转 90° 不是倒装 180°。** `mediad/src/main.rs:82`：
> 「**90, because the head camera is mounted a quarter turn off**, and this is the one place
> that fact is written down.」`docs/project/media-bringup.md:472` 里的 180° 是 **alpha 机**的过时数据。

| 店铺 | 价格 | 销量 | 链接 |
|---|---|---|---|
| DECXIN旗舰店 | ¥32.8 | 100+ | [tmall 775872575316](https://detail.tmall.com/item.htm?id=775872575316) |
| 德创信摄像头 | ¥32.8 | 27 | [taobao 771618094322](https://item.taobao.com/item.htm?id=771618094322) |
| 盛成威科技（11年老店） | ¥38 | 84 | [taobao 596521821696](https://item.taobao.com/item.htm?id=596521821696) |
| 亚博智能（14年老店，有技术文档） | ¥44 | 15 | [taobao 709927597121](https://item.taobao.com/item.htm?id=709927597121) |
| 树莓派零售商（包邮，48h发） | ¥68 | 100+ | [taobao 760446989892](https://item.taobao.com/item.htm?id=760446989892) |
| findboard旗舰店（瑞莎官方版） | ¥129.99 | 9 | [tmall 874789708454](https://detail.tmall.com/item.htm?id=874789708454) |

### 排线：15 针 ⇄ 22 针转接（可能需要，**买最短的**）

⚠️ **官方手册没给接口规格。** `Radxa ZERO 3W Product Brief` Rev 1.10 §6.3 原文只有：

> "The Radxa ZERO 3W is equipped with a **1x4-lane MIPI CSI** connector for camera integration.
> This interface is designed to be backward-compatible with standard industrial camera peripherals."

没有引脚数、没有间距。但 Zero 3W 是树莓派 Zero 形态，CSI 座与 Micro HDMI 同边、布局与 Pi Zero
一致，**极可能是窄口 22 针 0.5 mm**，而通用 IMX219 模组随附的是**标准 15 针 1.0 mm**。

> 💡 **买 15 cm 甚至更短的就够** —— 摄像头和主控在同一个刚体里，相距约 13 mm，
> 排线**不穿过脖子**。别买 30 cm。

| 店铺 | 说明 | 长度 | 价格 | 链接 |
|---|---|---|---|---|
| **汇博视捷科技工厂店** | 15转22Pin 金手指 FPC，**4 cm 短版** | 4cm | **¥1.88** | [taobao 654755002992](https://item.taobao.com/item.htm?id=654755002992) |
| 摄像头生产厂家（11年老店） | Pi Zero Camera Cable | 16cm | ¥1.88 | [taobao 819560127110](https://item.taobao.com/item.htm?id=819560127110) |
| **Tytion（15年老店）** | 标题明确写 **15P 1.0 转 22P 0.5** | 15cm | ¥2.5 | [taobao 678057486394](https://item.taobao.com/item.htm?id=678057486394) |
| 树莓派精品销售商（13年老店，包邮） | 官方线，135/200/300/500 mm 可选 | 多档 | ¥5.8 | [taobao 784739658496](https://item.taobao.com/item.htm?id=784739658496) |

---

## 四、ToF 测距 · VL53L8CX（8×8 多区）

固件同时支持 **VL53L5CX 和 VL53L8CX**，按 revision ID 自动识别
（`tof/src/sensor.rs:70-100`：`0x0C = L8cx` / `0x02 = L5cx`）。
I²C 地址候选 **`0x29` 或 `0x52`**（`tof/src/main.rs:87`），挂在 i2c3 @ 400 kHz。
HAT 上走 **JST SH 1.0 mm 4P**（Qwiic / Stemma QT）接口 J5–J8。

| 店铺 | 型号 | 价格 | 销量 | 链接 |
|---|---|---|---|---|
| 森科源电子 | VL53L8CX | ¥70 | 1 | [taobao 1025775539663](https://item.taobao.com/item.htm?id=1025775539663) |
| 深圳市渱雯电子 | VL53L8CX | ¥74.98 | 0 | [taobao 977907234039](https://item.taobao.com/item.htm?id=977907234039) |
| 都会明武电子（包邮，回头客2万） | VL53L7CX / **L8CX** | ¥75 | 100+ | [taobao 942554129061](https://item.taobao.com/item.htm?id=942554129061) |
| 深圳优信电子（技术文档，包邮，对公） | VL53L8CX | ¥78.5 | 31 | [taobao 967946231167](https://item.taobao.com/item.htm?id=967946231167) |
| 勇泰发电子（11年老店，包邮） | VL53L8CX | ¥84.8 | 14 | [taobao 939165242465](https://item.taobao.com/item.htm?id=939165242465) |
| 归吉星旗舰店 | ST 官方 P-NUCLEO-53L8A1 评估套件 | ¥98 | 1 | [tmall 725486284128](https://detail.tmall.com/item.htm?id=725486284128) |

> ⚠️ **别买成 VL53L0X。** 搜「VL53L5CX」出来的绝大多数是 **VL53L0X —— 单点测距**，固件不认。
> 也注意 **VL53L7CX ≠ VL53L8CX**（L7 是 90° 视场的另一颗），有些链接把 L7/L8 混在一个宝贝里，选 SKU 看清。
> 见过一条 ¥8 的「VL53L5CX」标题里同时写着「79GHz 雷达传感器」—— 关键词堆砌的坑货。

---

## 五、电源

| 件 | 店铺 | 价格 | 销量 | 链接 |
|---|---|---|---|---|
| **NP-F 电池仓（取电用）** | 腾壶旗舰店 | ¥17.8 | 99 | [tmall 658975825526](https://detail.tmall.com/item.htm?id=658975825526) |
| **NP-F 供电扣板**（Type-C 快充） | 拓普赛旗舰店 | ¥19 | 58 | [tmall 926961598924](https://detail.tmall.com/item.htm?id=926961598924) |
| NP-F550 电池本体 | 唯卓仕（国标 3C，带电量显示） | ¥52.8 首单 | 900+ | 搜「唯卓仕 NP-F550」 |

> 💡 **这两条正好补上上游缺的一环。** 官方只给了打印件 `power_support`（×2），
> **没有触点模型**，取电方案原本要自己解决 —— 直接买现成扣板即可。
>
> ⚠️ **是 NP-F550 不是 F970。** 上游网格文件名叫 `np_f970` 是误导：实测包围盒
> **38.6 × 20.6 × 70.8 mm** 就是 F550 的尺寸（索尼官方规格：F550 = 38.4×20.6×70.8，
> F970 = 38.4×**60.0**×70.8）。源码全库 grep 只有 2 处命中、**都是 NP-F550**
> （`robotd-design.md:572`、`duck-control/src/model.rs:108`「NP-F550, 2S Li-ion」），F970 零命中。
>
> 电池**外挂在机身后下方**，71 mm 长有约 40 mm 悬在躯干壳体下沿之外，由两片
> 83.5 mm 长的 `power_support` 从外面夹住。

### 降压模块（不打 HAT 时给主控供 5 V）

HAT 上的 `U9 AP63205` 是给主控出 5 V 的，[不打 HAT](不打HAT.md) 就得买个现成模块顶上。

| 件 | 规格 | 价格 | 搜索词 | 链接 |
|---|---|---|---|---|
| **UBEC 5V/3A**（首选） | 输入 **≥ 覆盖 6–8.4 V**，输出 5 V 3 A，带屏蔽和磁环 | ¥10–15 | 「UBEC 5V 3A 2S」 | *待补* |
| MP1584EN 模块（备选） | 输入 4.5–28 V，输出 5 V 固定或可调，标 3 A（无散热实际 ~2 A） | ¥3–5 | 「MP1584EN 5V」 | *待补* |

**买之前看这三个数，不看牌子：**

1. **输入电压下限 ≤ 6 V** —— 2S 电池带载能跌到 6.6 V，舵机同时启动时更低。很多 UBEC 标「2–6S」，实际下限写的是 7 V，**2S 快没电时它先掉出稳压、主控重启**。商品页找「输入电压」那一行，下限必须 ≤ 6 V
2. **输出电流 ≥ 2 A 连续** —— Radxa Zero 3W 跑 NPU + 摄像头 + WiFi 峰值 1 A 出头，官方 HAT 用的就是 2 A 的 AP63205。标 3 A 的小模块无散热实际 1.5–2 A，所以 UBEC 优先
3. **同步降压** —— 效率 90%+。**别买 LM2596**：150 kHz 非同步、压差要 1.5 V 以上，6 V 进 5 V 出已经在边缘，还发热

输入端并一个 **470 µF / 16 V** 电解，缓冲 15 颗舵机同时启动时的压降 —— 见 [不打 HAT · 第 3 步](不打HAT.md#第-3-步--电源每接一段量一次)。

---

## 六、两块 PCB

### RPI Robot HAT —— 买不到，只能打样；但你不一定需要它

**官方不单卖。** Pollen 只卖整机 Microduck，HAT 没有零售页。oshwhub 上也没搜到有人复刻。

**① 忠实打样** —— 官方给了完整生产文件（Gerber + BOM + 贴片坐标，Apache-2.0）。
实测核对：**4 层板**（`F_Cu / In1_Cu / In2_Cu / B_Cu`）、板框 **65.0 × 30.9 mm**、圆角 **R3.5**、
BOM **47 行 / 123 颗**（其中 5 行 9 颗 DNP）、实际贴装 **113 个位置**。加 SMT 成本几百元起且有起订量。

**② 用现成模块顶掉 —— ¥50 以内**

HAT 实际功能（逐条对原理图核过）：

| 功能 | 还需要吗 | 现成替代 |
|---|---|---|
| **舵机总线半双工 TTL** —— U5 `74LVC1G08` + U6 `SN74LVC1G125` + U7 `SN74LVC1G126`，<br>由 `DynUART_Tx`/`DynUART_Rx`/`Dynamixel_dir` 控方向 | ✅ 必需 | 见下表 |
| **配电** —— `+BATT` 直供舵机；U9 `AP63205` + L4 6.8µH → `+5V` 上 40-pin 给主控；<br>U3 `XC6206P182` → `+1V8` 给 codec | ✅ 必需 | 现成 UBEC（5V/3A 以上） |
| **音频** —— U2 `TLV320AIC3104`（i2c3 0x18 + i2s3_2ch）、U1 `PAM8406D` 功放、<br>MK1 MEMS 麦克风、Wago 端子接 5W 喇叭与外接麦 | ❓ 看需求 | **不要录音喇叭就整块省掉** |
| **传感器扩展** —— J5–J8 JST SH 1mm 4P（Qwiic/Stemma）接 ToF | ✅ 需要 | 直接挂 i2c3，几根线 |
| 板载 U11 `BMI088` | ❌ **贴了但软件不用**（`i2c3-pihat.dts:11`「dormant」、`:31`「unused but still connected」） | — |
| U4 `CAT24C32` EEPROM | ❌ **DNP 不贴** —— 所以这块板**不是自识别 HAT** | — |

**舵机连接器**：J13 / J14 = **JST EH 3P**（TTL，经 TH1 100R 热敏到 `+BATT`）；
J3 / J11 = **JST EH 4P**（RS-485，由 U8 `SIT3088E` 驱动，直接 `+BATT`），原理图旁注 **「3A max」**。

**半双工总线转接板**（走飞特路线直接对口）：

| 店铺 | 说明 | 价格 | 链接 |
|---|---|---|---|
| Fashion脖子（13年老店，90付款） | 串口总线舵机驱动板，**适用 ST/SC 系列** | **¥22** | [taobao 1005305041207](https://item.taobao.com/item.htm?id=1005305041207) |
| 众灵科技企业店（200+付款） | ZLink USB/TTL 调试板 + 总线舵机转接 | ¥22.5 | [taobao 570100064201](https://item.taobao.com/item.htm?id=570100064201) |
| 芯板坊（7年老店） | 微雪 串口总线舵机驱动板，适用 ST/SC | ¥24 | [taobao 954634564409](https://item.taobao.com/item.htm?id=954634564409) |
| 灵影智能企业店（200+付款） | ST/SC 飞特总线舵机 TTL 驱动板 `TTL_Adapter_(A)` | ¥26 | [taobao 983866781632](https://item.taobao.com/item.htm?id=983866781632) |

> 💡 **走飞特路线的话这条特别值得考虑。** `imu_to_dxl` 要重画、策略要重训、设备树也要改 ——
> HAT 同样该重新评估。¥22 的转接板 + 一个 UBEC 就顶掉了「舵机总线」和「配电」两件必需功能。
> 代价是失去板载音频。

### imu_to_dxl —— 自绘

STM32G031F8P6 + LSM6DSV16X + 半双工缓冲，对外表现成总线从机（Dynamixel 侧 ID 200）。
协议与寄存器布局已完整还原，见 [硬件方案逆向](硬件方案逆向.md)。

- **打样成本**：2 层板，嘉立创约 ¥25–40（不含贴片）
- **双协议**：要同时支持飞特与 Dynamixel 的话，**硬件不变、固件分支** ——
  两者物理层完全相同（半双工单线 TTL / 1 Mbps / 3 线），差别只在包格式
  （V2 包头 `FF FF FD 00` + CRC-16；飞特 `FF FF` + `~sum`）
- ✅ **接口与脚序已由官方规格书确认** —— 飞特《HL-2915-C002 串型规格书》A/0（2026-02-27）
  第 4 页 6-7 项：连接器 **`AMP-3`**，**`1=GND / 2=Vcc / 3=Signal/TTL`**，与 Dynamixel 一致。
  `HD-1910-C001.stp` 里连接器零件名为 `AMP-3P`，且该装配体含 `HL-2915-C002_ASM`，两款共用平台。
  <br>同规格书还确认：半双工异步、8bit/1stop/无校验、**出厂默认 1 Mbps**、ID 0–253（默认 1）、
  信号高电平 **2–5 V**（本板 74LVC 输出 3.3 V 在窗口内；输入耐 5.5 V 也扛得住舵机的 5 V）
  <br>⚠️ 该规格书是 HL-2915-C002（**12 V**），电气参数不可套用到 HD-1910（5–8.4 V）
  <br>⚠️ 「飞特 = TTL 单线」只对 STS/SCS/HL 成立 —— 官方手册写明 **SMS 系列走 RS485、默认 115200**
- **连接器壳体仍要实物试插** —— 飞特线材标 **5264 端子**，官方 HAT 用 **JST EH**，
  两者**都是 2.5 mm 间距**但不同系列，卡扣和壳体外形不同。舵机和线到手后试插一次，
  插不上就把 J1/J2 从 `B3B-EH-A`（`C160259`）换成 5264-3P。
  PR #12 那版图上是 JST PH 2.0 mm，**间距就不对，要改**
- **C6（LDO 输入电容）耐压 10 V → 25 V** —— 总线满电 8.4 V，10 V 余量不够（MLCC 还有直流偏压衰减）
- **C5 用 4.7 µF 不是 100 nF** —— ST DS12992 Rev 3 Fig.13 对 `VDD/VDDA` 的要求是
  `1 × 100 nF + 1 × 4.7 µF`，两颗一样的 100 nF 并联不顶用。选立创基础库 `C19666`
- **U1 的 2、3 脚留有源晶振焊盘（不贴）** —— TSSOP20 没引出 `OSC_OUT`，无源晶振接不了；
  HSI16 精度最坏 −1.85%/+1.55%（Table 41），1 Mbps 够用但余量不多
- **DATA 线加 TVS** —— 带电插拔舵机是常态
- **协议靠软件自动识别，不加拨码开关/跳线** —— 两家包头都是 `FF FF`，Dynamixel V2 后面跟 `FD 00`，飞特跟的是 `ID`+`LENGTH`（LENGTH 恒 ≥ 2，所以 `FD 00` 无歧义）。收前 3 包投票锁定，之后按锁定协议收发。拨码开关在会走路的机器人里是振动失效点，而且这板一辈子只配一次
- **J3 用 6P 不用 4P** —— 多出的 4/5 脚是 `USART1_TX/RX`（U1 脚 16/17 重映射），插个 5 块钱 USB-TTL 就能看 printf。G031 没有 USB 外设，加 USB 口要多一颗桥接芯片，不值

---

## 七、线材与工具

| 件 | 店铺 | 说明 | 价格 | 链接 |
|---|---|---|---|---|
| **舵机总线连接线** | 深圳飞特舵机工厂店 | 三针四针 **5264 接口** | **¥1.8** | [taobao 616460581906](https://item.taobao.com/item.htm?id=616460581906) |
| 舵机线材 | 鸿翊电子舵机工厂店 | 飞特串口总线，3针/4针 5264 端子 | ¥2.5 | [taobao 769633088382](https://item.taobao.com/item.htm?id=769633088382) |
| 舵机连接线（多长度） | 松甲科技（300+付款） | 母对母 **5264-3P**，10/15/20/30/50/70 cm | ¥2 | [taobao 587191439333](https://item.taobao.com/item.htm?id=587191439333) |
| **FE-URT-1 调试板** | 深圳飞特舵机工厂店（官方店） | USB 转 485/TTL | **¥45** | [taobao 603181554943](https://item.taobao.com/item.htm?id=603181554943) |
| URT-2 调试板 | 深圳飞特舵机厂家 | 同类 | ¥45 | [taobao 575365901461](https://item.taobao.com/item.htm?id=575365901461) |
| URT 调试板（第三方） | 云驱者科技企业店 | 同类 | ¥40 | [taobao 712781832610](https://item.taobao.com/item.htm?id=712781832610) |

> **调试板是必需品** —— 舵机到货第一件事是实测总线时序。
>
> ⚠️ **这不是飞特独有的问题。** 官方 Dynamixel 路径同样是**每设备一次应答延迟** ——
> `duck-control/src/model.rs:84-86` 写着 XL330 出厂 `return_delay_time = 250`，
> 即 **500 µs/设备**，「Across **16 devices** that is **8 ms per tick — 40% of a 20 ms budget**」，
> 官方的解法是把这个寄存器写 0（在 `EXPECTED_REGISTERS` 里）。
> **飞特侧已查清**：STS/SCS 有 `SYNC READ`（`0x82`），且 Return Delay Time 出厂就是 0 ——
> 见 [硬件方案逆向 · 飞特 STS/SCS 协议对照](../docs/硬件方案逆向.md)。所以更要实测，不能假定它一定更慢。

---

## 八、避坑

1. **摄像头排线别买长的** —— 主控和摄像头同在头部、同一刚体，MIPI 线不过脖子。4–15 cm 足够。
2. **摄像头是转 90° 不是 180°** —— 见上文。
3. **VL53L0X 冒充 VL53L5CX** —— 搜出来大多是单点的 L0X，固件不认；L7CX 也不是 L8CX。
4. **Radxa 裸板溢价** —— 官方分销 $22–70（¥158–504），淘宝在售 ¥690–1469。换渠道。
5. **泰山派装不进去** —— 不只是贵，是头部根本没有 70×45 的位置。
6. **¥8 的飞特 STS3215 / ¥22 的泰山派** —— 都是 SKU 诱导，点进去最低档是配件。
7. **乐泰 243 低于 ¥15 的要当心假货**（见 [机械采购清单](机械采购清单.md)）。

---

## 未验证项

- 全部价格、销量、店铺信息与链接有效性（2026-09-04 快照）
- Pollen 是否单卖 HAT
- Zero 3W 的 CSI 座究竟是 15P 还是 22P（官方文档未给，本文标为「极可能 22P」）
- 泰山派的规格、价格、开源工程内容

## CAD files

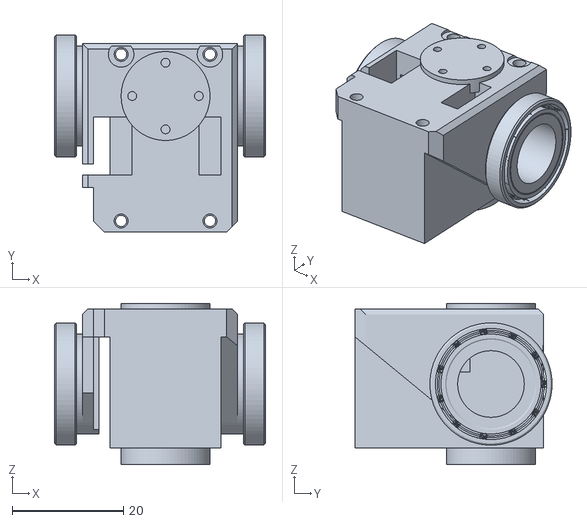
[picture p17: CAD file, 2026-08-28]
cad/09_头yaw-roll.stl
38.0 x 35.5 x 29.0

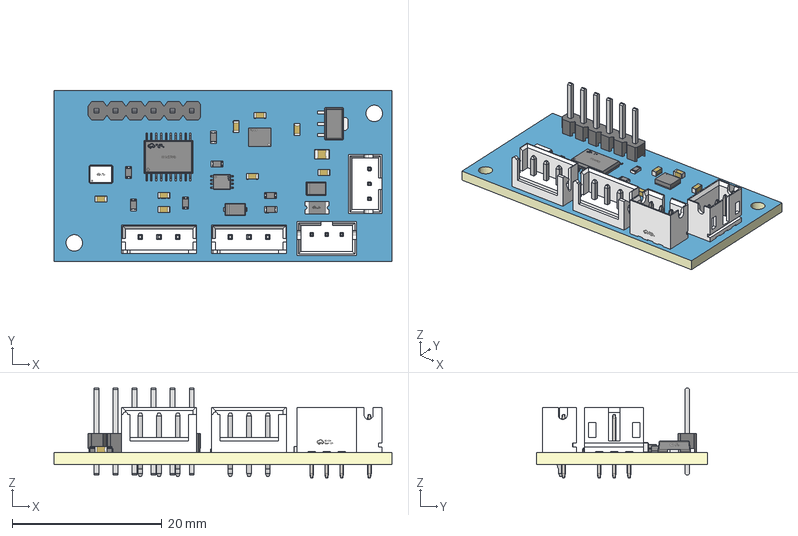
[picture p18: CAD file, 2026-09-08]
hardware/imu_to_dxl/imu_to_dxl-PCB.step
45.1 x 22.7 x 12.0 mm
Board~ss66
TopCopper~ss66
BottomCopper~ss66
TopSilkscreen~ss66
BottomSilkscreen~ss66
TopFpcStiffener~ss66
BottomFpcStiffener~ss66
C0805~C0805_L2.0-W1.3-H1.3~nCY8
SOD-123FL_L2.7-W1.8-LS3.7-RD~SOD-123FL_L2.8-W1.8-H1.1-LS3.6~Ts2a
LGA-14_L3.0-W2.5-P0.50-BR~LGA-14_L3.0-W2.5-P0.50-BR~xgQh
CONN-TH_B3B-EH-A-LF-SN~CONN-TH_B3B-EH-A-LF-SN~hPIn x 2
R0603~R0603~2pOD x 7
HDR-TH_6P-P2.54-V-M~HDR-TH_6P-P2.54-M-LI-1X6P~mF3L
VSSOP-8_L2.3-W2.0-P0.50-LS3.1-BR~VSSOP-8_L2.3-W2.0-P0.50-LS3.1-BL~MIWO
SOD-123_L2.7-W1.6-LS3.7-RD~SOD-123_L2.7-W1.6-H1.4-LS3.7~0OJw
TSSOP-20_L6.5-W4.4-P0.65-LS6.4-BL~TSSOP-20_L6.5-W4.4-H1.0-LS6.4-P0.65~VWKP
C0603~C0603_L1.6-W0.8-H0.8~crEB x 8
CONN-TH_B3B-PH-K-S~CONN-TH_B3B-PH-K-S~Q7be x 2
SOT-89-3_L4.5-W2.5-P1.50-LS4.2-BR~SOT-89-3_L4.3-W2.5-H1.6-LS4.1-P1.50~uLfP
OSC-SMD_4P-L3.2-W2.5-BL_SIT8008BI~OSC-SMD_4P-L3.2-W2.5-H1.0~S9ms
F1206~F1206_L3.2-W1.7-H0.6~vEE0

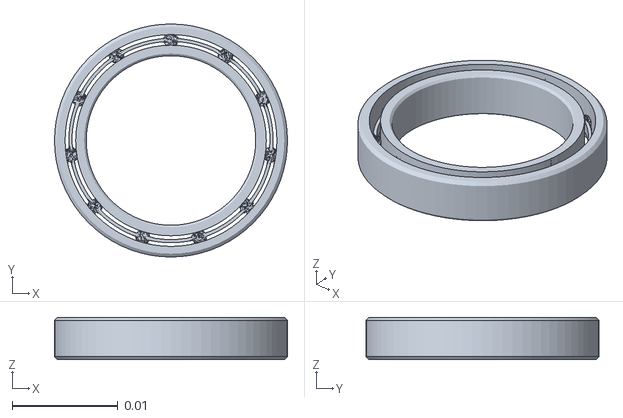
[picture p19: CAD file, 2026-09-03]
software/training/src/mjlab_microduck/robot/microduck/assets/seeed_bearing__configuration__22x16x4.stl
0.022 x 0.022 x 0.004

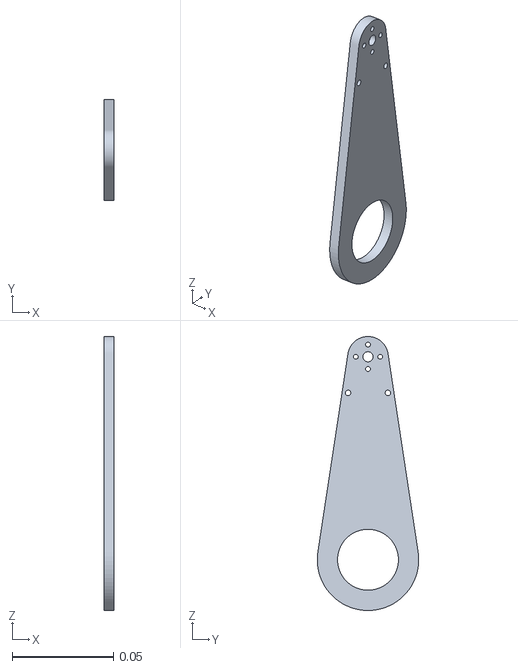
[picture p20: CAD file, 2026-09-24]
software/training/src/mjlab_microduck/robot/xl330_test_bench/assets/arm.stl
0.005 x 0.05 x 0.135

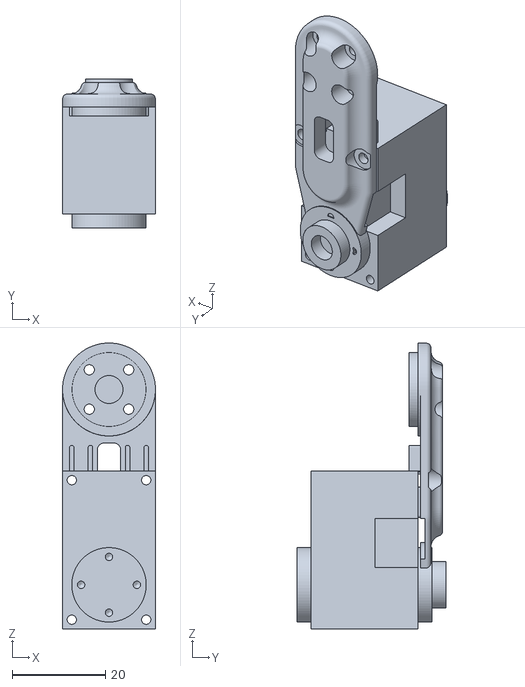
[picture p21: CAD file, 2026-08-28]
cad/14_右小腿.stl
20.0 x 32.0 x 61.5

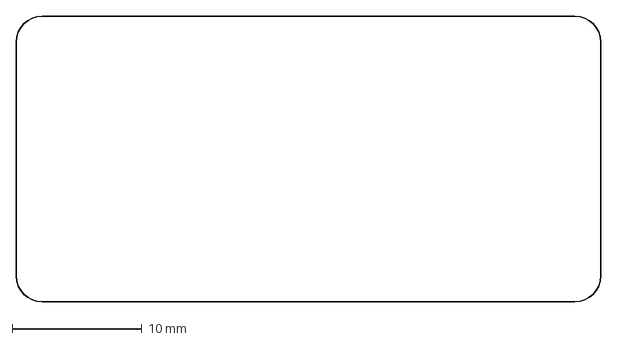
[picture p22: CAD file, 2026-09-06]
hardware/imu_to_dxl/imu_to_dxl-板框-45x22-R2.dxf
45.0 x 22.0 mm

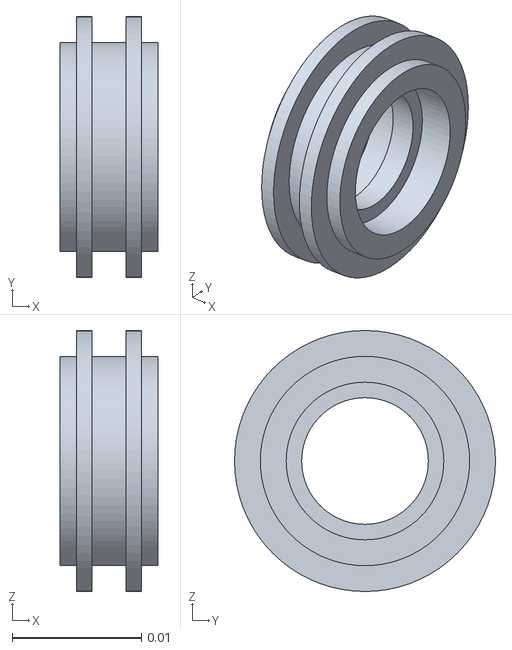
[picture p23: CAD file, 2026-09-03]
software/training/src/mjlab_microduck/robot/microduck/assets/rim.stl
0.0076 x 0.0202 x 0.0202

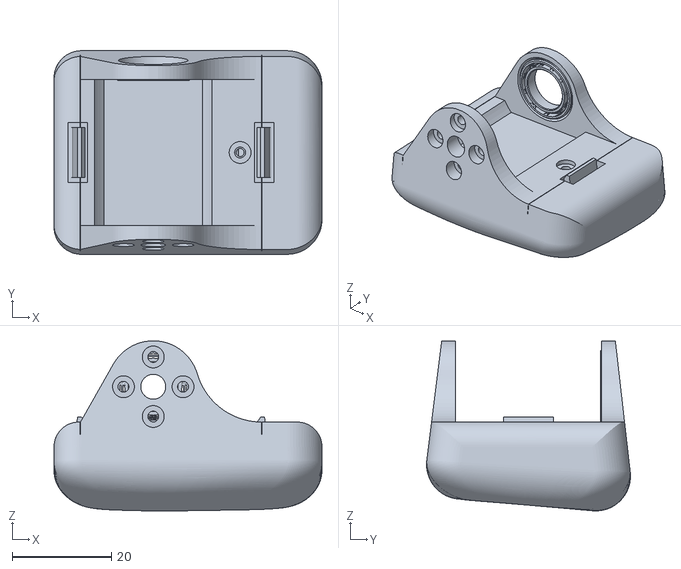
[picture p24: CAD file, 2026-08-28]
cad/15_右踝脚.stl
54.0 x 41.1 x 34.2

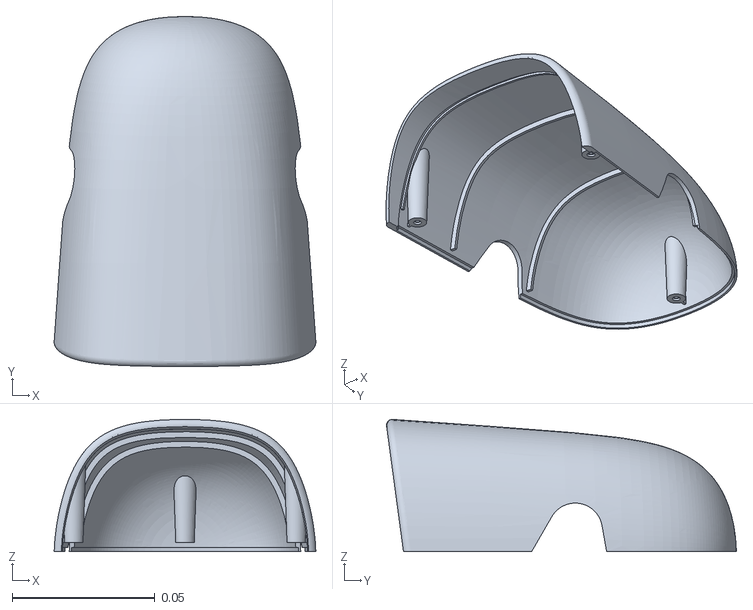
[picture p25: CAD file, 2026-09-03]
software/training/src/mjlab_microduck/robot/microduck/assets/top_head_shell.stl
0.0918 x 0.123 x 0.0463

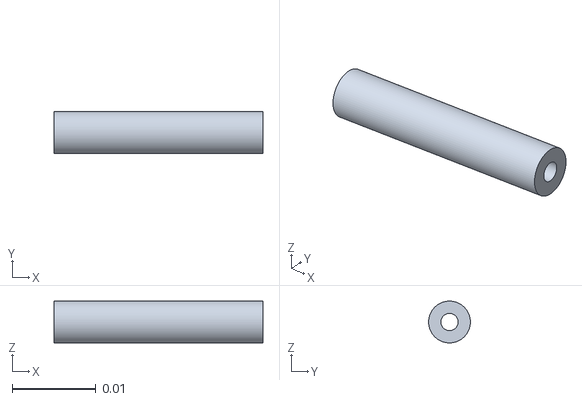
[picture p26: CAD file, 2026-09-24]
software/training/src/mjlab_microduck/robot/xl330_test_bench/assets/spacer.stl
0.025 x 0.005 x 0.005

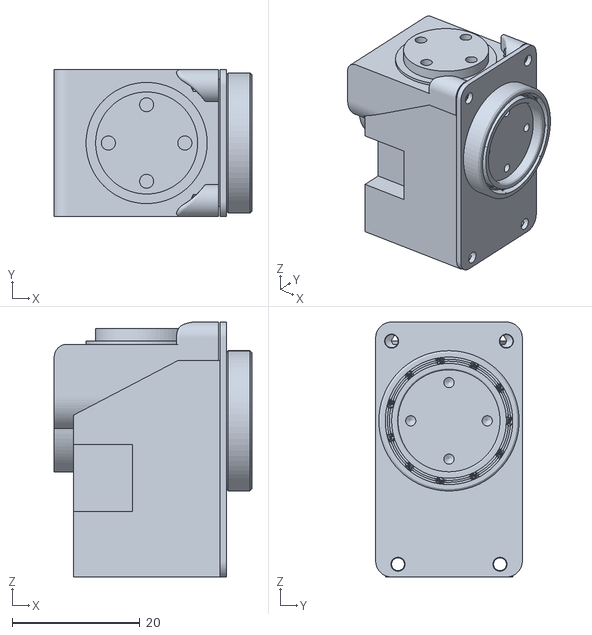
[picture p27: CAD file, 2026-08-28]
cad/02_左髋yaw-roll.stl
31.0 x 23.0 x 40.0

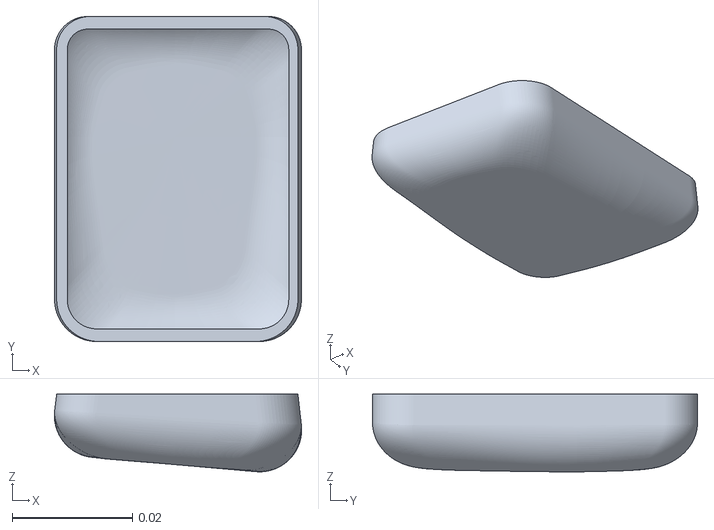
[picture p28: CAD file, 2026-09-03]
software/training/src/mjlab_microduck/robot/microduck/assets/sole_right.stl
0.0411 x 0.054 x 0.0129

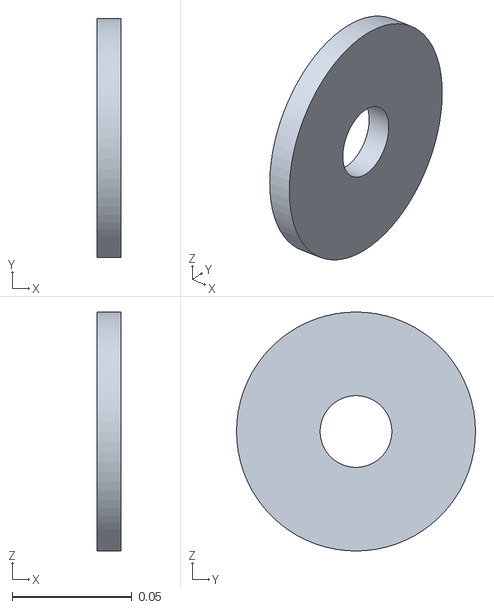
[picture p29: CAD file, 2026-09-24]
software/training/src/mjlab_microduck/robot/xl330_test_bench/assets/weight.stl
0.01 x 0.1 x 0.1

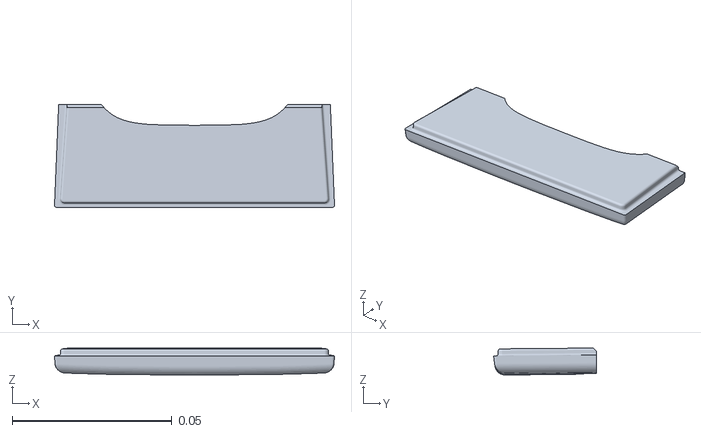
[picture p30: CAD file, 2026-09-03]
software/training/src/mjlab_microduck/robot/microduck/assets/jaw_soft.stl
0.0877 x 0.0322 x 0.00844

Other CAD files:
cad/06_左踝脚.stl
software/training/src/mjlab_microduck/robot/xl330_test_bench/assets/axis.stl
cad/07_颈根.stl
cad/01_躯干主体.stl
cad/03_左髋roll.stl
cad/04_左大腿.stl
cad/05_左小腿.stl
cad/08_颈俯仰.stl
cad/10_头部总成.stl
cad/11_右髋yaw-roll.stl
cad/12_右髋roll.stl
cad/13_右大腿.stl
software/training/src/mjlab_microduck/robot/microduck/assets/ankle_l_v1.stl
software/training/src/mjlab_microduck/robot/microduck/assets/ankle_left.stl
software/training/src/mjlab_microduck/robot/microduck/assets/ankle_r_v1.stl
software/training/src/mjlab_microduck/robot/microduck/assets/ankle_right.stl
software/training/src/mjlab_microduck/robot/microduck/assets/banana_pcb_locker.stl
software/training/src/mjlab_microduck/robot/microduck/assets/bearing_roll.stl
software/training/src/mjlab_microduck/robot/microduck/assets/bottom_head_shell.stl
software/training/src/mjlab_microduck/robot/microduck/assets/elec_rpi_robot_hat_pcb.stl
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

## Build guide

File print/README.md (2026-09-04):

# 3D 打印件

> 🛒 耗材、紧固件、热熔螺母与压头的采购链接见 [机械采购清单](../docs/机械采购清单.md)。

**简体中文** · [English](README.en.md)

整机全部 STL，按「**要打印**」和「**买现成的**」分好类，文件名中英双语。

| 目录 | 数量 | 说明 |
|---|---|---|
| [`打印件/`](打印件/) | **30 种 / 41 件** | 步行装配体需要的结构件。**有 9 种要打多份，务必看下面的数量表** |
| [`变体-轮滑/`](变体-轮滑/) | 5 种 / 15 件 | 轮滑功能的替换件，不做轮滑就不用打 |
| [`标准件-无需打印/`](标准件-无需打印/) | 8 | 舵机、轴承、电池、电路板的模型，**仅供对位和干涉检查** |
| [`上游已删除/`](上游已删除/) | 2 | 任何装配体都不引用，上游 2026-09-01 已移除。存档用 |

## ⚠️ 打几个：8 种零件要打多份

数量取自上游 `robot_walk.xml` 的 geom 引用计数，不是估的。

| 零件 | 数量 |
|---|---|
| `leg_腿部` | **×4** |
| `hip_l_髋部左` | ×2 |
| `neck_颈部` | ×2 |
| `power_support_电源支架` | ×2 |
| `sole_left_左脚底` | ×2 |
| `sole_right_右脚底` | ×2 |
| `upper_leg_rigidity_plate_上腿加固板` | ×2 |
| `yaw2roll_偏航转横滚` | ×2 |
| `bearing_roll_横滚轴承压盖` | ×2 |
| 其余 21 种 | 各 ×1 |

**轮滑变体**：`tire_轮胎` **×8**、`rim_轮辋` **×4**、`roller_blade` ×2、`ankle_l_v1`/`ankle_r_v1` 各 ×1。

> ⚠️ 轮滑脚踝比标准脚踝**高 10 mm**（46.5 vs 36.5），两套不能混用。

完整物料清单（含舵机、轴承、螺丝、电子件）见 [`../BOM.md`](../BOM.md)。

## 文件名规则

```
upper_leg_left_左上腿.stl
└──── 上游原名 ────┘└─中文─┘
```

前半段是上游 `microduck_rl` 里的原始文件名，方便和 MJCF、源码对照；后半段是中文，方便直接看懂是什么件。

## 与上游的差异

抓取时上游 `robot/microduck/assets` 有 **47 个 STL**，这里保留 **46 个**。

**去掉的 1 个重复**：右上腿在上游有 `upper_leg_right` 与 `right_upper_leg` 两个文件，
面数（12250）、包围盒、质心完全一致 —— 同一几何体的两次导出，只保留 `upper_leg_right`。

**分类调整**：轮滑专用件移入 `变体-轮滑/`；两个任何 MJCF 都不引用、且上游已删除的躯干壳
移入 `上游已删除/`。

> 上游的 XL330 台架测试夹具（`bench_holder`、`weight`、`spacer`、`axis`、`arm`、`part_1..5`）
> 在另一个目录 `robot/xl330_test_bench/assets`，不属于机器人，本来就不在这 47 个里。

## 打印建议

本仓库暂无官方打印参数（上游没有公开）。已知的实测信息见 [`../构建日志.md`](../构建日志.md)。

几个从结构上能看出来的点：

- **头壳、躯干壳**是外观件，建议层高 0.12–0.16 mm
- **腿部结构件**承力，建议加大壁厚和填充
- **`soft_mouth_top` / `jaw_soft`** 名字带 soft，原版应为软性材料（TPU 类）
- **`tire_轮胎`** 同理，轮滑用的胎，硬材料打出来会打滑
- 打印件上的 M2 孔位建议用**热熔螺母**而不是直接攻丝，螺丝清单见 [`../docs/紧固件反推.md`](../docs/紧固件反推.md)

## 授权

这些 STL 是上游 `pollen-robotics/microduck_rl` 公开发布文件的**衍生作品**（重命名与分类整理），
遵循与上游一致的 **CC BY-NC-SA 4.0**：署名、相同方式共享、非商业使用。

详见 [`../NOTICE.md`](../NOTICE.md)。

---

## 勘误（2026-09-04）

`bearing_roll` 此前被归入 `标准件-无需打印/`（当成买现成的轴承），**这是错的**。判据：

1. **几何** —— 实测 **23 × 3 × 40 mm**、带 Ø≈18 mm 中心孔的平板，体积 625 mm³（填充率 23%）。
   没有任何标准轴承是这个形状；两颗真轴承实测是 22.0/**16.0**/4.0 与 15.0/**10.0**/3.0 的回转体。
2. **出处** —— `assets/*.part` 的 Onshape `elementId`：`bearing_roll` 与 `trunk_base`、`yaw2roll`、
   `left_shell`、`right_shell`、`power_support`、`neck` 同属 `d6fcdccc8b25aaa256e7e213`
   （自建打印件的躯干 Part Studio）；两颗真轴承在 `92eaf48a756ec816309fc756`，
   带配置串 `..._22x16x4` / `..._Default`，是典型标准件配置库。
3. **装配** —— 它与 `yaw2roll` 在同一个 body、同一个 `pos`，quat 只差整体符号（同一旋转），
   是贴在 yaw2roll 侧面、往下多伸 19.5 mm 的一块盖板 —— 功能上是 hip_roll 轴那颗
   Ø22 轴承的**压盖/挡板**（Ø18 孔小于 Ø22 外径，正好挡住外圈）。

原中译「轴承滚轮」也错了 —— 既不是轴承也不是滚轮，已改为「横滚轴承压盖」。
打印件计数因此 **29 种 / 39 件 → 30 种 / 41 件**，标准件 **9 → 8**。

> 另注：`robot_walk.xml:264` 里右腿 hip_yaw 那个 link 被 onshape-to-robot 命名成
> `<body name="bearing_roll">`，但它内部的可视件是 `yaw2roll_2` —— 这只是链接命名巧合，
> 与零件性质无关。

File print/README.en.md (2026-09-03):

# 3D-Printable Parts

[简体中文](README.md) · **English**

Every STL for the whole robot, split into **print these** and **buy these**, with bilingual filenames.

| Directory | Count | What it is |
|---|---|---|
| [`打印件/`](打印件/) (print) | **37** | Structural parts you print yourself |
| [`标准件-无需打印/`](标准件-无需打印/) (do not print) | **9** | Models of bought parts — servos, bearings, battery, PCBs. **For fit and interference checking only** |

> These are **individual parts**, for printing.
> For **assembly relationships** see [`../cad/`](../cad/) — 16 sub-assemblies merged along the kinematic tree.

## Filename convention

```
upper_leg_left_左上腿.stl
└─ upstream name ─┘└ zh ─┘
```

The first half is the original filename from `microduck_rl`, so it cross-references the MJCF and the
source; the second half is Chinese, so a Chinese-speaking builder can tell what it is at a glance.

## Differences from upstream

Upstream `microduck_rl` ships **53 STLs**. This directory carries **46**.

**The 7 left out** are XL330 test-bench fixtures, not robot parts:

```
bench_holder  weight  spacer  axis  arm  part_1 … part_5
```

**One duplicate removed**: the same left upper leg ships upstream under two names
(`upper_leg_left` and `left_upper_leg`), byte-for-byte identical. Only
`upper_leg_left_左上腿.stl` is kept here.

> ⚠️ **Do not mistake `upper_leg_left` and `upper_leg_right` for the same part** — they are
> different geometry. You need both.

## Printing notes

No official print settings exist (upstream never published any). Measured findings so far are in
[`../BUILD-LOG.en.md`](../BUILD-LOG.en.md).

A few things the geometry itself tells you:

- **Head and trunk shells** are cosmetic — 0.12–0.16 mm layers
- **Leg structural parts** carry load — increase perimeters and infill
- **`soft_mouth_top` / `jaw_soft`** are named *soft*; the originals are presumably a flexible
  material (TPU family)
- **`tire_轮胎`** likewise — a roller-skating tyre printed in rigid filament will simply slip
- Use **heat-set inserts** for the M2 holes rather than tapping the plastic. Screw list:
  [`../docs/fastener-reconstruction.en.md`](../docs/fastener-reconstruction.en.md)

## Licence

These STLs are a **derivative** (renaming and sorting) of files published by upstream
`pollen-robotics/microduck_rl`, and carry the same **CC BY-NC-SA 4.0** terms: attribution,
share-alike, non-commercial.

See [`../NOTICE.md`](../NOTICE.md).

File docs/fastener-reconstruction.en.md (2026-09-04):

# Fastener Reconstruction

> ⚠️ **This English version lags behind the Chinese original.** Several corrections (camera rotation, MK1 part number, U10 placement, STS3032 torque basis, board SKU) were applied to the Chinese docs first. **When the two disagree, the Chinese version wins.** Last sync: 2026-09-05.

[简体中文](紧固件反推.md) · **English**

There is no mechanical BOM upstream and no screw list (the HAT board has an electronics BOM, but it covers no structural parts). Everything below was **recovered from the
geometry of the 47 STL meshes.**

## Method

`scripts/analyze_holes.py`:

1. Weld duplicate vertices, build a face-adjacency graph
2. Cut at a 35° dihedral angle and region-grow "smooth surface patches" (breaks at sharp
   edges)
3. Fit a cylinder to each patch — a cylinder's face normals are all perpendicular to its
   axis, so **the axis is the smallest eigenvector of the normal covariance matrix**
4. Project the vertices onto the plane perpendicular to that axis and fit a circle
   (Kåsa algebraic fit) for the diameter; discard anything with >3 % relative residual
5. Normals pointing toward the axis = **a hole**; pointing away = a shaft or boss, excluded
6. Measure angular coverage and keep only complete circles (≥300°)

All 47 parts scan in 2.5 seconds.

## Conclusion: The Whole Robot Is an M2 System

Diameter distribution of complete circular holes across the structural parts:

| Diameter | Count | Reading |
|---|---|---|
| **Ø2.2** | **77** | **M2 clearance hole** (standard M2 clearance is 2.2–2.4) |
| **Ø4.4** | **28** | **M2 counterbore** (M2 socket-head cap dia. is Ø3.8; counterbore 4.0–4.5) |
| **Ø1.6** | **20** | **M2 tapping hole** (the standard M2 tap drill is exactly 1.6) |
| Ø2.4 | 22 | loose M2 clearance |
| Ø2.0 | 12 | tight M2 clearance |
| Ø2.7 / Ø2.8 | 20 | M2.5 clearance (a small number) |
| Ø4.8 | 10 | M2 counterbore, a second depth |
| Ø5.4 / Ø6.0 | 16 | shaft bores / bearing seats — not fasteners |

**Ø2.2 and Ø4.4 appear as a pair** on `yaw2roll`, `leg`, `ankle_left`, `neck_pitch` and
`yaw_roll_motion` — the classic **clearance hole + counterbore** combination, which
confirms **M2 socket-head cap screws**.

Cross-check: `xl330.stl` itself carries **4× Ø2.0 + 8× Ø1.6**, matching the Dynamixel
XL330's own M2 mounting pattern.

## Per-Part Hole Counts

Weighted by how many times each mesh is actually used in the full robot:

| Mesh | Uses | M2 clearance | M2 tap | Counterbore |
|---|---|---|---|---|
| `xl330` | **×15** | 4 | 8 | — |
| `hip_l` | ×2 | 9 | — | 6 |
| `yaw2roll` | ×2 | 8 | — | 6 |
| `leg` | ×2 | 6 | — | 6 |
| `neck_pitch` | ×1 | 12 | — | 4 |
| `face_part` | ×1 | 10 | 4 | — |
| `ankle_left` / `ankle_right` | ×1 each | 5 | — | 5 |
| `yaw_roll_motion` | ×1 | 4 | — | 6 |
| `power_support` | ×1 | — | 8 | — |
| `left_shell` / `right_shell` | ×1 each | 7 / 6 | — / 1 | — |
| `bearing_roll` | ×2 | 4 | — | — |
| `neck` | ×2 | 4 | — | — |
| `upper_leg_rigidity_plate` | ×2 | 4 | — | — |
| `jaw` | ×1 | 5 | — | — |
| `trunk_base` | ×1 | 4 | — | — |
| `bottom_head_shell` / `top_head_shell` | ×1 each | 4 / 3 | — | — |
| `m12_lens_holder` | ×1 | 3 | — | — |

> **`xl330` appears 15 times** — the robot has 15 servos, not 14. Fourteen are under policy
> control; the fifteenth drives the beak/jaw through a `passive_*` linkage and never enters
> the action space. This matches the "15 servos" in the official README.

## Purchase Estimate

- M2-class holes (Ø1.9–2.5 mm, ≥300° wrap) across the assembly, **weighted by usage: 237**,
  of which 60 are on the servo bodies (15×4), 21 on bought parts (bearings / PCBs / battery),
  and about 156 on printed structural parts

  > ⚠️ **Correction (2026-09-04)**: earlier versions said "213", which does not reconcile. Two
  > causes: the earlier count was **not weighted by how often each part is used** (`leg` is ×4,
  > `hip_l` and `yaw2roll` are ×2), and it **included meshes no MJCF references**. The diameter
  > and depth tables below are **unweighted** (each STL counted once) — the two cannot be summed.
  themselves (15 × 4)
- Excluding servos and bought-in parts (bearings, PCBs, battery), the structural parts
  account for **roughly 146 clearance holes**

**Suggested quantities** (including losses and trial fitting):

| Spec | Suggested | For |
|---|---|---|
| M2×4 socket head | 60 | thin-wall positions (51 of 79 holes are 0–3 mm deep) |
| M2×6 socket head | 80 | the workhorse size |
| M2×8 socket head | 40 | 3–5 mm deep positions (24 of 79) |
| M2×12 socket head | 15 | a few deep holes (8–12 mm, 4 places) |
| M2 nuts | 50 | where there is nothing to tap into |
| M2 heat-set inserts | 60 | recommended over tapping printed plastic directly |
| M2.5×6 | 20 | the handful of Ø2.7 positions |

Lengths are inferred from the measured depth distribution of the Ø2.2 holes: 51 at
0–3 mm, 24 at 3–5 mm, 4 at 8–12 mm.

## Bearings

| Source file | Measured |
|---|---|
| `seeed_bearing__configuration__22x16x4` | **OD 22 × ID 16 × W 4 mm** |
| `seeed_bearing__configuration_default` | OD 15 × ID ~10 × W 3 mm (×3 in the robot) |

## ⚠️ Limitations

1. **This is recovered from simulation meshes, not from engineering drawings.** Simulation
   meshes only guarantee correct outer shape and inertia — not fit tolerances or complete
   thread detail.
2. **Print shrinkage changes the real hole size.** A Ø2.2 design hole typically comes out
   0.1–0.3 mm undersize on FDM. Print a test piece and check before committing to a build.
3. **Counterbores and clearance holes may be double-counted** (two features of the same
   screw). Screw counts here are based on clearance holes only; counterbores are not
   counted separately.
4. **Features not detected:** non-circular holes (slots, shaped cutouts), partial arcs with
   <300° coverage, and openings larger than Ø14 mm are all outside the statistics.
5. Screw **lengths** are ranges inferred from hole depth, not measured values.

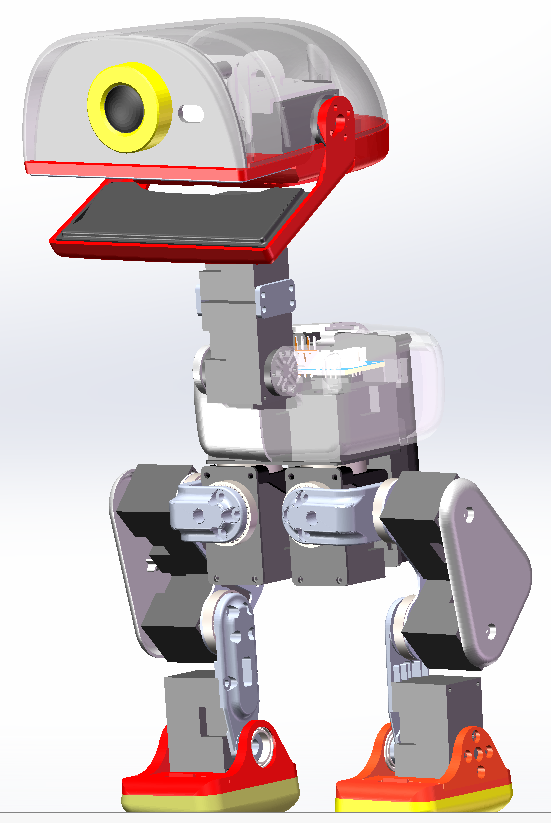
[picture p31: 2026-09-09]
assets/cad-solidworks-装配体.png

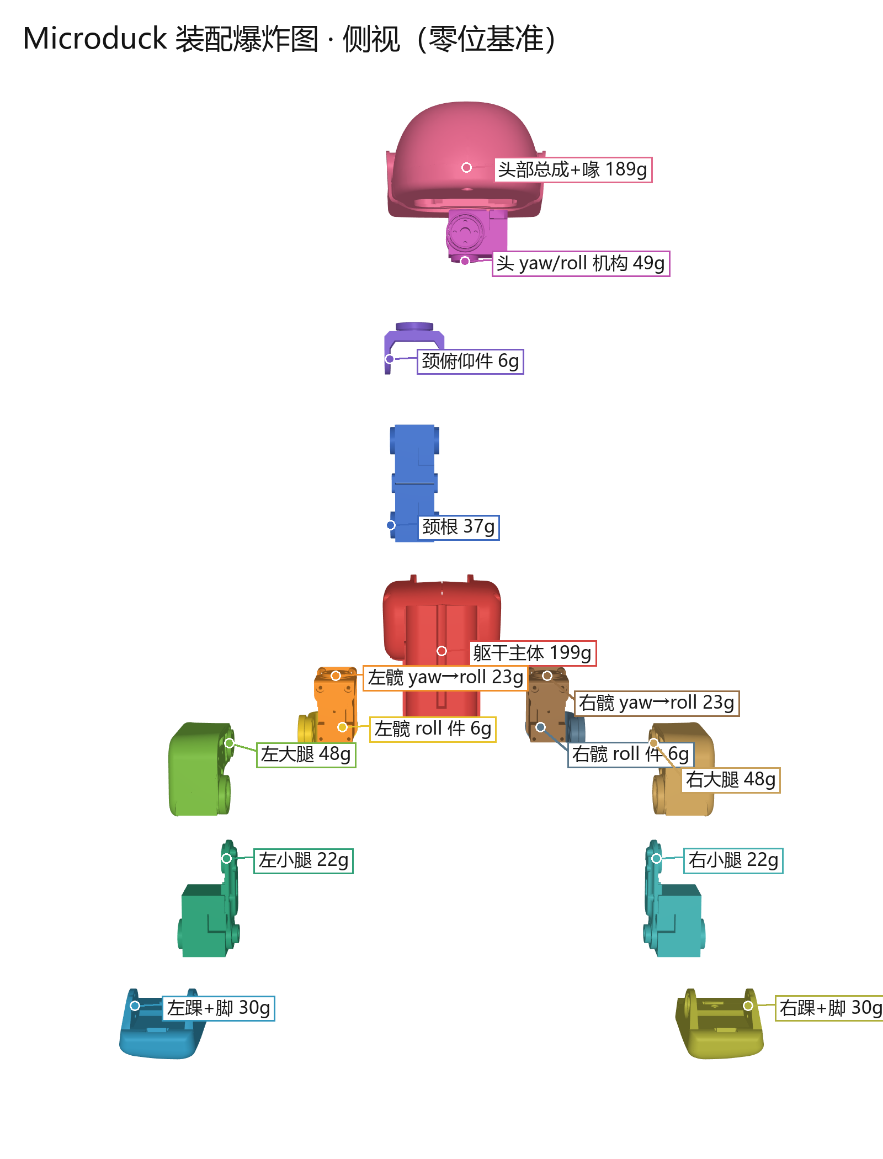
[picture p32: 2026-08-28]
assembly-drawings/05_爆炸图_侧面.png

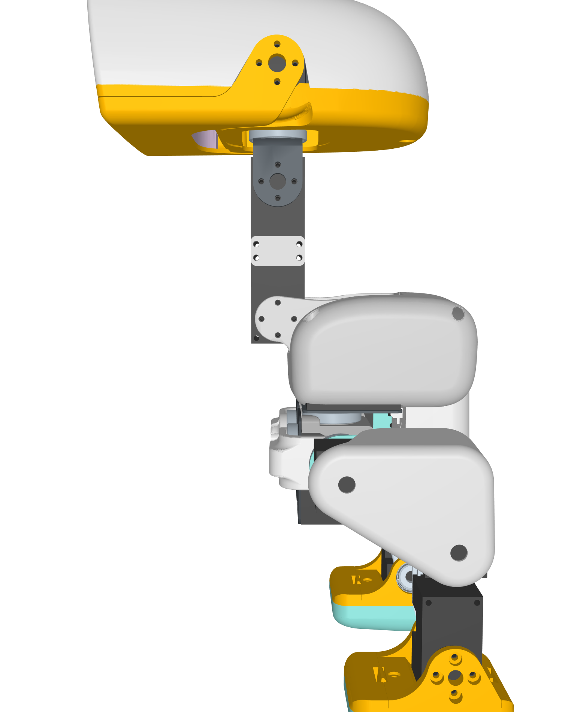
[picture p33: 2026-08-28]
assembly-drawings/03_背面.png

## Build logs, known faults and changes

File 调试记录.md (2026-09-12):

# 调试记录

**简体中文**

> **当前状态：全部器件到齐，主控排针已焊，舵机在装机械件**
> 最后更新：2026-09-12

[构建日志](构建日志.md) 记的是**机械**：打印、试装、公差。
这份记的是**电气与软件**：先是**一步一步的操作手册**（拿到货怎么配、怎么接、怎么测），下面是**按日期的过程**（做了什么、看到什么、下一步是什么）。

结论性的坑单独整理在 [踩坑记录](踩坑记录.md)。板子和芯片是什么、为什么这么选，在 [硬件入门](docs/硬件入门.md)。

---

## 进度

| 日期 | 阶段 | 状态 | 备注 |
|---|---|---|---|
| 2026-09-10 | 舵机 + 调试板到货 | ⚠️ 遇到问题 | 调试板 TTL 口跟舵机 2.0 mm 线不匹配 |
| 2026-09-12 | 主控、ToF、电池、电池仓、SD 卡、排针、摄像头到齐 | ✅ 完成 | 排针已焊到 Radxa 上 |
| 2026-09-12 | 舵机装机械件 | 🔨 进行中 | **HD-1910 跟 XL330 有结构差异**，改件重打后可适配 |
| — | 逐个配 ID | 📋 计划中 | 等转接线 |
| — | 主控刷机（2G 板 / microSD） | 📋 计划中 | **卡在没读卡器**，买了再做 |
| — | `imu_to_dxl` 板上电 | 📋 计划中 | 等打样回来 |
| — | 不打 HAT 飞线接主控 | 📋 计划中 | 等转接板、降压模块；步骤已写好 ↓ |

图例：📋 计划中 · 🔨 进行中 · ✅ 完成 · ⚠️ 遇到问题 · ❌ 此路不通

---

## 手头有的

| 东西 | 数量 | 状态 |
|---|---|---|
| 飞特 HD-1910-C001 | 15 | ✅ 到货 2026-09-10 |
| 飞特 FE-URT-2 调试板 | 1 | ✅ 到货 2026-09-10 |
| Radxa Zero 3W 2 GB（裸板，无 eMMC） | 1 | ✅ 到货 2026-09-12，**排针已焊** |
| Radxa Zero 3W 8 GB + 64 GB eMMC | 1 | 📦 月底 |
| NP-F550 电池 + 电池仓 | — | ✅ 到货 2026-09-12 |
| VL53L8CX ToF | 1 | ✅ 到货 2026-09-12 |
| 摄像头 | 1 | ✅ 到货 2026-09-12 |
| 高耐久 microSD | — | ✅ 到货 2026-09-12 |
| 2×20 排针 | — | ✅ 到货并焊上 |
| `imu_to_dxl` PCB + SMT | 5 | 🏭 立创生产中，¥629.72 |
| 读卡器、转接线、降压模块、半双工转接板 | — | 📋 待买 |

---

## 飞特资料在哪

本地 `飞特-HD1910/` 只有规格书 PDF、DWG、STP。**软件和手册在 Gitee，不在官网**：

| 要什么 | 在哪 |
|---|---|
| **FD 调试软件** + **CH340 驱动** | **仓库里就有：[`tools/飞特/`](tools/飞特/)**（FD 1.9.8.5 + 驱动，MIT，带 sha256）。原始出处 [gitee.com/ftservo/fddebug](https://gitee.com/ftservo/fddebug) |
| 例程 / 通信协议 / 内存表 | [gitee.com/ftservo](https://gitee.com/ftservo) 各仓库 |
| 官网软件页（备用） | [feetech.cn/software.html](https://www.feetech.cn/software.html) |
| 入手教程 PDF | [先看这里-入手教程](https://www.feetech.cn/Data/feetechrc/upload/file/20220618/%E5%85%88%E7%9C%8B%E8%BF%99%E9%87%8C-%E5%85%A5%E6%89%8B%E6%95%99%E7%A8%8B2-1.pdf) |

---

## 舵机配置 · 拿到货一步一步做

**目标**：15 颗 HD-1910 每颗设好 ID、打开保护、贴上标签，装机时拿起来就知道它是哪个关节。

### 需要什么

| 东西 | 说明 |
|---|---|
| HD-1910-C001 × 15 | 出厂 ID **全是 1** |
| FE-URT-2 调试板 + USB-C 线 | 用左边两个白色 3 针口（丝印 `TTL-Bus`，`G V1 S`）。右边 4 针是 RS485，不用 |
| 一根剪开的舵机线 | 调试板的口跟舵机 2.0 mm 线**插不上**，得飞线。15 根牺牲一根 |
| 电源 | 三选一，见第 3 步。**只配 ID 的话 USB 就够** |
| 软件 | [`tools/飞特/`](tools/飞特/)：FD 1.9.8.5 + CH340 驱动，Windows |
| 万用表 | 量电压、查线序 |
| 标签纸 + 笔 | 第 7 步用 |

### 第 1 步 · 装软件

```
1  插上 URT-2 → 设备管理器「端口」里出现 USB-Enhanced-SERIAL CH343 (COMx)，记下号
   URT-2 是 CH343，Win10/11 自带驱动，不用装。没出现才装 tools/飞特/CH340_URT.rar（老款 URT-1 用）
2  解压 tools/飞特/FD1.9.8.5(250729).7z → 直接运行，不用安装
```

### 第 2 步 · 飞线

剪一根舵机线，一头是 2.0 插头、另一头三根裸线。**认脚号，别认颜色**：

```
舵机线                       URT-2
脚 1  Signal / TTL    →    S     焊到板背面白口 S 脚的焊点上（临时：线头镀锡后插进白口 S 孔）
脚 2  Vcc             →    V1    蓝色接线端子
脚 3  GND             →    G     蓝色接线端子
```

- **中间那根一定是 V**，飞特和 Dynamixel 在这点上一致 —— V 放错才会烧
- S 和 G 接反了**不会烧**，只是搜不到，对调即可
- 脚 1 在插头上有小三角或缺口标记，或看舵机本体插座旁丝印

### 第 3 步 · 供电

**⚠️ 先量再接。** 调试板上那个拨动开关是把 USB 5 V 连到 V1 用的。开关在 USB 侧、又往 V1 灌外接电压，**等于把 7.4 V 反灌进电脑 USB 口**。

```
USB 插上、外电源不接、量蓝色端子 G–V1：
   ≈5 V  →  开关在 USB 侧。只配 ID 到这就够了，不用外电源
   0 V   →  开关在外接侧。要接外电源才能工作
```

| 用什么 | 怎么接 | 什么时候用 |
|---|---|---|
| **USB 5 V** | 开关拨到 USB 侧，不接别的 | **配 ID、改参数**。HD-1910 从 4 V 起工作，空载够 |
| 可调开关电源 | 开关拨到外接侧。设 **7.4 V、限流 2 A**，+ 接 V1、− 接 G | 看它转、测力矩 |
| NP-F550 电池 | 开关拨到外接侧。经取电扣板，+ 接 V1、− 接 G | 同上，真实工况 |

**别在满电 8.4 V 的电池上做堵转测试** —— 那是 HD-1910 电压上限，零余量。

### 第 4 步 · 搜舵机

```
1  FD 里选第 1 步记下的 COM 口
2  波特率 1000000
3  点「打开」
4  只接一颗舵机（飞好线那根）
5  点「搜索」→ 列表里出现 ID 1，型号 HD-1910
```

搜不到，按顺序查：驱动装没装 → COM 口选对没 → 波特率是不是 1000000 → S 线接触好不好（临时插孔的最可疑）→ S/G 是不是反了。

### 第 5 步 · 改参数

切到「编程」页（EPROM）。**每颗都改这几项，别的别动：**

| 参数 | 出厂 | 改成 | 为什么 |
|---|---|---|---|
| **ID** | 1 | **按下表** | 官方运行时按这个 ID 找关节 |
| **过流保护** | 关 | **开** | 装机后堵转是常事，不开就是烧舵机 |
| **过压保护** | 关 | **开** | 8.4 V 满电落在 4–10 V 窗口内，不会误触发 |
| 过热保护 | 开（80 ℃） | 不动 | — |
| 波特率 | 1 Mbps | 不动 | 出厂就是官方要的 |
| 运行模式 | 模式 4 纯位置 PD | 不动 | 正是强化学习落地要的那个 |
| Return delay | 0 | 不动 | STS 系列上这项不起作用 |
| 中位 | — | **装机时再校** | 用 FD 的「中位校准」，装好舵盘再点 |

改完点「保存」。

**ID 对照表** —— 来自上游 `duck-control/src/model.rs`，注释说数值是「对着硬件量出来的」：

| ID | 关节 | ID | 关节 | ID | 关节 |
|---|---|---|---|---|---|
| **10** | 右髋 yaw | **20** | 左髋 yaw | **30** | 颈俯仰 |
| **11** | 右髋 roll | **21** | 左髋 roll | **31** | 头俯仰 |
| **12** | 右髋 pitch | **22** | 左髋 pitch | **32** | 头 yaw |
| **13** | 右膝 | **23** | 左膝 | **33** | 头 roll |
| **14** | 右踝 | **24** | 左踝 | **34** | 嘴 |

**记法**：十位 = 部位（1 右腿 · 2 左腿 · 3 颈头），个位 = 从躯干往末端数（0 髋 yaw → 4 踝）。
ID 200 是 `imu_to_dxl` 板，固件里写死，不在这里配。

### 第 6 步 · 验证

```
1  断电（拔 USB 或关电源）
2  重新上电
3  再点「搜索」→ 新 ID 出现了才算写进去了
```

这步别省，EPROM 参数要断电重启才确定。

### 第 7 步 · 贴标签，下一颗

标签写**关节名 + ID**（比如「左膝 23」），别只写数字。15 颗长得一模一样。
拔掉，换下一颗，回第 4 步。一颗约两分钟。

### 第 8 步 · 看它转（可选）

搜到舵机后在主页面点它，拉位置滑杆它就跟着转。USB 5 V 空载能转但没力；接了 7.4 V 才是真实工况。

---

---

## 不打 HAT · 飞线接主控

**单独成文了 → [docs/不打HAT.md](docs/不打HAT.md)**。很多人觉得 HAT 打样太贵，那份就是替代方案：¥70 的模块、一步一步接、哪步会烧东西。
这里只记做的时候发生了什么。

---

## 2026-09-10 · 舵机和调试板到了

**到了什么**：15 颗 HD-1910-C001，一块 FE-URT-2 调试板（USB-C，TTL 和 RS485 口都有）。

**第一个问题**：舵机原装线是 **2.0 mm 3P**（规格书写的 AMP2.0-3P），调试板左边那两个白色 TTL 口**比这个大，插不上**。板子没给 2.0 的口。

**怎么办**：买「舵机转接线 2.0 转 2.5 3P」。等线的期间要动手就剪两根线对焊。
`imu_to_dxl` 板的 J4/J5 是 PH 2.0 mm，跟舵机线是配的，**不受影响** —— 只是这块调试板的口不对。

**下一步**：转接线到了逐个配 ID。**一次只接一颗**（出厂 ID 全是 1），改完贴标签。
顺手把每颗的过流、过压保护打开（出厂默认关）。波特率和运行模式出厂就是对的，不动。
步骤和 ID 表见上面 [舵机配置 · 拿到货一步一步做](#舵机配置--拿到货一步一步做)。

---

## 2026-09-12 · 器件到齐，主控排针焊好，舵机开始装机械件

**到了什么**：Radxa Zero 3W（2 GB 裸板）、ToF、电池、电池仓、microSD、排针、摄像头。加上 09-10 的舵机和调试板，**除了 `imu_to_dxl` 板（立创还在做）和飞线模块（降压、转接板、转接线），全齐了**。

**做了什么**：
- 2×20 排针焊到 Radxa 上了
- 开始把飞特 HD-1910 往机械件里装

**发现的问题**：**HD-1910 跟原版 XL330 在结构上有差异**（压腿那一处）。同事改了结构件重新打印，改后能装。
具体哪个件、改了哪里、改了多少 —— *待补*（拍照、量尺寸，写进 [构建日志](构建日志.md)，同时在 [执行器选型](docs/执行器选型.md) 的 HD-1910 那节加一条「机械上不是直接替换，要改件」）。

**下一步**：
- 舵机继续装，装完一条腿先量一次活动范围
- 配 ID —— 转接线还没到，先按 [上面第 2 步](#第-2-步--飞线) 剪一根舵机线飞过去。**今天先做这个**
  - ✅ 线飞好了，拨码拨到 USB 侧，G–V1 量到 5 V
  - ✅ 插电脑出 **COM5**，芯片是 **CH343**（不是 CH340），Win 自带驱动直接认 —— 手册第 1 步已改
- 主控刷机 —— **没读卡器，做不了**。卡是 microSD，板子自己不能当读卡器用；笔记本没 SD 槽的话得买一个（USB 3.0 的）。到了按 [不打 HAT · 第 1 步](docs/不打HAT.md#第-1-步--主控点亮什么都别接) 点亮

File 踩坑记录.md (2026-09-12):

# 踩坑记录

复刻过程中真踩过的坑，**每条三句：现象、原因、怎么办**。按阶段分，上手前扫一遍。

分析和证据在别的文档里，这里只记结论。有新坑往对应阶段里加，写直白点。

> 时间顺序的构建过程在 [构建日志](构建日志.md)。

---

## 买东西

**电池别买 NP-F970，是 NP-F550**
上游网格文件名叫 `np_f970.stl`，但量出来是 39 × 21 × 71 mm，这是 F550 的尺寸。真 F970 厚约 60 mm，**装不进去**，而且 300 g 会吃掉整机预算的三分之一。
→ 买 NP-F550（2S，6.6–8.4 V）。详见 [BOM](BOM.md)。

**飞特 HD-1910 的线是 2.0 mm，飞特调试板的口不是 —— 配 ID 得飞线**
HD-1910 原装线是 AMP2.0-3P（2.0 mm 间距）。FE-URT-2 调试板的 TTL 口比这个大，**插不上**，板子也没给 2.0 的口。
→ 当天就要配 ID 的话，**剪一根舵机线**（15 根牺牲一根），三根裸线这么接：

```
舵机线                  FE-URT-2
脚 1  Signal    →   S    焊到板背面白口 S 脚的焊点上（临时也可镀锡后直接插进 S 孔）
脚 2  Vcc       →   V1   蓝色接线端子
脚 3  GND       →   G    蓝色接线端子
```

**中间那根一定是 V**（飞特和 Dynamixel 在这点上一致），S 和 G 接反了不会烧、只是通不了，对调即可。
**V 接错才会烧。** 配 ID 空载，USB 5 V 够用（HD-1910 从 4 V 起工作）—— 先用万用表量蓝色端子 G–V1 有没有 5 V，没有就拨那个开关。
→ 正式的做法是买「PH2.0 3P 端子线」+ 板子那种规格的端子线各几根，对焊成转接线。买前翻翻舵机包装盒，有时附一根。
→ 这条值得直接告诉飞特：正式版是否附转接线。

**飞特脚序跟 Dynamixel 完全相反**
飞特 HD-1910：`1=Signal 2=Vcc 3=GND`。Dynamixel XL330：`1=GND 2=Vcc 3=Signal`。
→ 好在两种间距不同（2.0 vs 2.5 mm）插不进对方。只剩「自己压线时压反」这一种可能 —— 压完先用万用表点一遍。

**别拿 HL-2915 当参考**
飞特 HL-2915-C002 是 9–14 V 舵机，2S 电池（最高 8.4 V）**带不动它**，而且它的脚序又跟 HD-1910 相反。
→ 本方案只认 HD-1910-C001。

**电池满电 8.4 V 正好等于 HD-1910 的电压上限**
HD-1910 工作范围 4–8.4 V。NP-F550 满电 8.4 V，**零余量**。带载压降到 6.6–8.2 V 才回到安全区。
→ 刚充满别直接堵转测试。长期存放按 3.8 V/cell 存。装机前把舵机的过压保护打开。

**Radxa Zero 3W 低配版是裸板**
2 GB 无 eMMC 版本**没焊排针、没有存储**，只能 microSD 启动。
→ 自己买 2×20 排针（2.54 mm，立式，买彩色的好数脚）和**高耐久** microSD（SanDisk High Endurance / 海康 PLUS，32 或 64 GB，买两张一张做备份）。

**飞特舵机出厂 ID 全是 1**
15 颗一起接上去，全都应答，分不出谁是谁。
→ **设 ID 时一次只接一颗。** 改完贴标签（写关节名 + ID），拔掉，换下一颗。步骤和 ID 表见 [调试记录 · 舵机配置](调试记录.md#舵机配置--拿到货一步一步做)。

---

## 画板 / 打板

**立创下单页的「替换」不回写工程**
下单页点「替换」换料号，只对那一单生效。EasyEDA 工程里的元件还是旧料号，**下次导 BOM 又变回去**，再报一次「私有库 0」。
→ 在 EasyEDA 工程里把元件换掉（删了重放同坐标），不要只在下单页换。

**有源晶振和无源晶体，3225 四脚长得一模一样**
无源晶体的 2 脚和 4 脚是同一片金属盖、内部短接。本板 X1 按有源画（2=GND，4=VDD），贴上无源的**一上电就是 3.3 V 对地短路**。立创搜「3225」出来大部分是无源，`C13738`（基础库免换料费）最容易顺手点错。
→ 只认标签写「有源晶振 / OSC」的。本板用 `C5917307`。

**星通时频 C387369 立创贴片备料库没有**
下单时被归到「使用私有库存的元器件」，私有库 0。
→ 换 `C5917307`（雅晶鑫，5 mA，同封装）。

**加了器件后 Gerber / BOM / 坐标全要重导**
改了原理图（比如加 J4/J5）后，三个文件都变了。用旧 Gerber 打板，板子上没那两个座子的孔。
→ 每次改完导出全套，文件名带时间戳，认最新的那份。

**GitHub Release 附件名里的中文会被清掉**
上传 `SolidWorks图纸.zip`，存成了 `SolidWorks.zip`。README 里写的下载链接对不上。
→ Release 附件直接用英文名。

---

## 飞线（不打 HAT 时）

> 完整接法在 [不打 HAT](docs/不打HAT.md)，这里只列会咬人的。

**转接板的逻辑供电只能取 3.3 V**
半双工转接板 MCU 侧有个 VCC。取 5 V 的话它的 TX 会用 5 V 电平打进主控 3.3 V 的 RX 脚。
→ 从 40 针 pin 1（3.3 V）取。ToF 从 pin 17 取，两个不抢。

**5 V 灌进 40 针是无保护的**
从 pin 2/4 喂 5 V 绕过了板子自己的 USB 输入保护。**接反当场烧板。**
→ 插之前先量降压模块输出的极性和电压。

**舵机主干别用杜邦线**
15 颗峰值好几安培，杜邦线 24–28 AWG 只扛 1 A 左右，会发烫甚至熔皮。
→ 主干用 18–20 AWG 硅胶线。

**电池到舵机那一路要串保险丝和开关**
锂电池短路会喷火。官方 HAT 那条路上有热敏 + 「3A max」标注，飞线方案裸接就什么都没有。
→ 串 5 A 保险丝 + 电源开关。

**没有关机检测信号**
HAT 上的 LM5050-1 给主控一个关机信号，飞线方案没有。每次断电都是硬拔，**最伤 microSD**。
→ 先 `make shutdown` 或手柄关机手势，等系统关干净再断电。

---

## 软件

**Armbian 出厂 `overlay_prefix=rk35xx`，RK3566 的 overlay 却叫 `rk3568-*`**
前缀不对，加载器什么都找不到、静默失败，板子正常启动，**但没有 `/dev/ttyS2`**。你会以为是线接错了。`apt upgrade` 换内核后可能打回原形。
→ `/boot/armbianEnv.txt` 里改成 `overlay_prefix=rk3568`，加 `overlays=uart2-m0`，重启。官方 `setup-board.sh` 就干这个。

**内核 console 默认也在 ttyS2 上**
UART2 是 RK3566 的调试串口，Armbian 把内核日志往那打 —— 也就是往舵机总线上打。
→ `/boot/armbianEnv.txt` 的 `extraargs` 里去掉 `console=ttyS2,1500000`。

**Armbian 默认在 UART2 上跑登录控制台**
`agetty` 占着 `/dev/ttyS2`，舵机怎么都不通。线接对了也不通，八成是它。
→ `systemctl mask serial-getty@ttyS2`，然后 `fuser -v /dev/ttyS2` 确认没别的进程。

**别关 armbian-zram-config**
Armbian 默认把日志放 zram（内存）里不落盘，是在保护 SD 卡。有人为了看日志方便把它关了，写入量翻几倍。
→ 留着。官方 `deploy/README.md` 原话：不落盘是「有意的安排」，关掉是「每块板自己的决定，不是默认」。

**i2c3 用 pin 3/5 会失去 USB-C PD 协商**
RK3566 的 i2c3 原厂跑在 M1 pinmux 服务 FUSB302（USB-C PD）。官方 overlay 把它 mux 到 M0（pin 3/5）并禁用 fusb302。
→ 接受这个代价：USB-C 仍给 5 V，只是不协商。机器人供电走电池，跟这无关。

---

## 工具

**VS Code 的 Markdown Editor 扩展不显示 HTML 图片**
README 用 `<table><img>` 拼的两栏卡片，那个扩展不解析裸 HTML 里的相对路径，图全空。GitHub 上是好的。
→ 用 VS Code 自带预览（`Ctrl+Shift+V`）。

**Windows 上 `core.autocrlf=true` 会毁掉二进制文件**
PDF 头部多为 ASCII，git 自动探测误判成文本，checkout 时做 LF→CRLF 转换，文件直接损坏。
→ `.gitattributes` 里把 `*.pdf *.stl *.step *.png` 等全部声明 `binary`。

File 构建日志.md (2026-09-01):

# 构建日志

**简体中文** · [English](BUILD-LOG.en.md)

> **当前状态：3D 打印中**
> 最后更新：2026-09-02　|　已有实物照片 ↓

本仓库的其余部分都是**纸上分析** —— 从公开的 MJCF 与源码反推出的几何、装配关系和电控方案。
这份日志记录的是**把它真正做出来**的过程：打了什么、装了什么、哪里出了问题。

> ⚠️ 本仓库反复强调过一个判断：**仿真 STL 不是可打印工程件** ——
> 仿真只保证外形与惯量，不保证配合公差、螺纹、埋件座和走线空间。
> **这份日志就是在验证这句话到底对不对。** 结论会如实写在这里，无论正反。

---

## 进度

| 日期 | 阶段 | 状态 | 备注 |
|---|---|---|---|
| 2026-09-01 | 首批零件打印 | 🔨 进行中 | 头壳、躯干壳、腿部结构件、脚 |
| 2026-09-02 | 腿部件试装 | 🔨 进行中 | **M2 螺丝已装入，孔位可用** |

图例：📋 计划中 · 🔨 进行中 · ✅ 完成 · ⚠️ 遇到问题 · ❌ 此路不通

---

## 打印记录

| 零件 | 材料 | 层高 | 填充 | 耗时 | 结果 |
|---|---|---|---|---|---|
| *(待填)* | | | | | |

**打印机 / 切片软件**：*(待填)*

---

## 踩过的坑

> 这一节是整份日志最有价值的部分 —— **别人可以不重复踩。**
> 每条按「现象 → 原因 → 解决」写，没解决的就写「未解决」。

### （待填）

**现象**：
**原因**：
**解决**：

---

## 尺寸与配合验证

反推出来的数据在实物上对不对：

| 项目 | 反推值 | 实测值 | 是否吻合 |
|---|---|---|---|
| 整机外形 | 144 × 141 × 264 mm | *(待测)* | |
| M2 过孔 | Ø2.2 mm | *(待测)* | |
| M2 沉头孔 | Ø4.4 mm | *(待测)* | |
| M2 攻丝底孔 | Ø1.6 mm | *(待测)* | |
| 轴承座 | Ø22 × 16 × 4 mm | *(待测)* | |

> FDM 打印通常会让孔径偏小 0.1–0.3 mm，这一栏的实测数据对后来者价值很大。

---

## 待解决

- [ ] *(待填)*

---

## 照片

### 2026-09-02 · 首批打印件

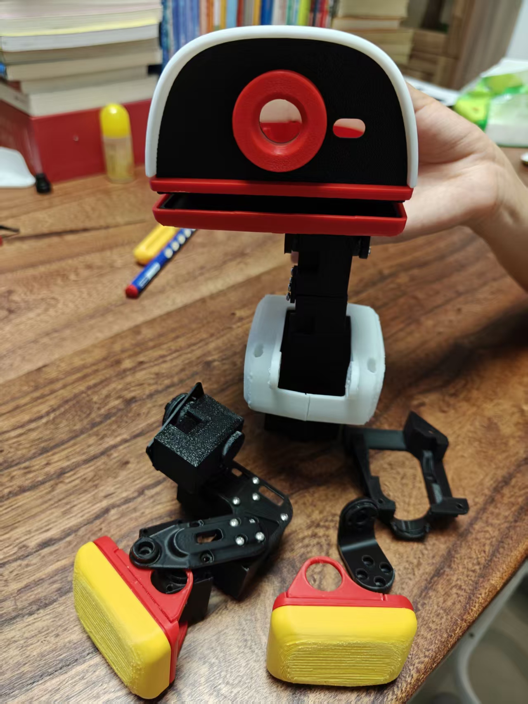
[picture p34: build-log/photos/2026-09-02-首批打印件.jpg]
首批打印件


已打印并部分装配的零件：

- **头部总成** —— 多色打印（白 / 黑 / 红），含摄像头环座与指示灯开口，表面质量良好
- **颈部** —— 黑色，已与头部连接
- **躯干外壳** —— 白色
- **腿部结构件** —— 黑色，**M2 螺丝已装入**
- **脚** —— 红 / 黄双色，两只

> 📌 **第一个实物验证点**：黑色腿部件上的 **M2 螺丝已经装进去了**。
> 这说明 [紧固件反推](docs/紧固件反推.md) 得出的「整机是 M2 螺丝系统」这个结论，
> 在实物上是成立的 —— 至少这几个孔位是。
>
> 精确孔径实测数据待补，见上方「尺寸与配合验证」表。

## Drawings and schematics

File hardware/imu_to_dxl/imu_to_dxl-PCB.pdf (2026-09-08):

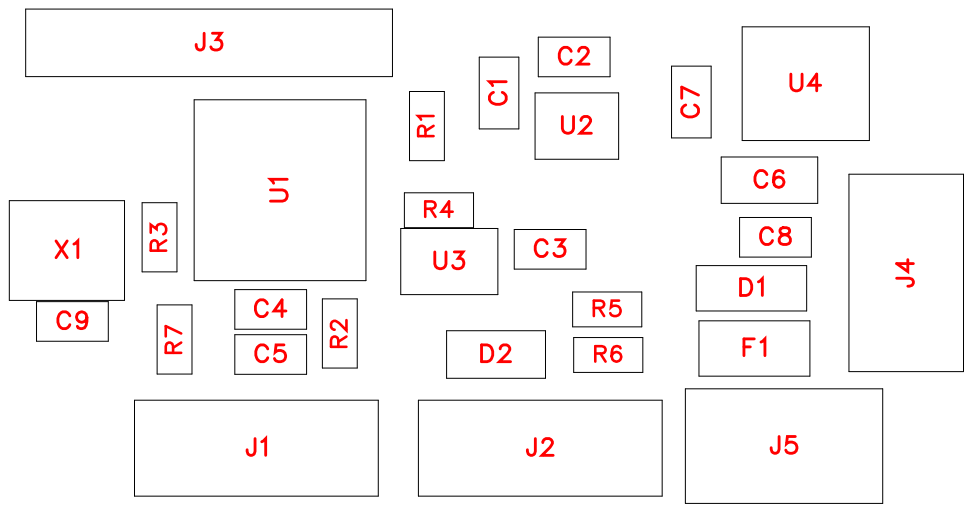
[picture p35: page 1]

No. | Quantity | Comment | Designator | Footprint | Value | Manufacturer Part | Manufacturer | Supplier Part | Supplier
1 | 6 | 100nF | C1,C2,C3,C4,C8,C9 | C0603 | 100nF | CC0603KRX 7R9BB104 | YAGEO(国巨 ) | C14663 | LCSC
2 | 1 | 4.7uF/16V | C5 | C0603 | 4.7uF/16V | CL10A475K O8NNNC | SAMSUNG( ) 三星 | C19666 | LCSC
3 | 1 | 10uF/25V | C6 | C0805 | 10uF/25V | CL21A106KA YNNNE | SAMSUNG( 三星 ) | C15850 | LCSC
4 | 1 | 10uF/10V | C7 | C0603 | 10uF/10V | CL10A106KP 8NNNC | SAMSUNG( 三星 ) | C19702 | LCSC
5 | 1 | SMF12A | D1 | SOD-123FL_ L2.7-W1.8-L S3.7-RD | | SMF12A | GOODWOR K(固得沃克 ) | C2943870 | LCSC
6 | 1 | BZT52C5V1-7-F | D2 | SOD-123_L2 .7-W1.6-LS3. 7-RD | 5V1 | BZT52C5V1-7-F | DIODES( 美 台 ) | C151588 | LCSC
7 | 1 | MF-NSMF02 0X-2 | F1 | F1206 | | MF-NSMF02 0X-2 | BOURNS | C210358 | LCSC
8 | 1 | 舵机总线进 | J1 | CONN-TH_B 3B-EH-A-LF-SN | | B3B-EH-A(L F)(SN) | JST | C160259 | LCSC
9 | 1 | 舵机总出线 | J2 | CONN-TH_B 3B-EH-A-LF-SN | | B3B-EH-A(L F)(SN) | JST | C160259 | LCSC
10 | 1 | PZ254V-11-0 6P | J3 | HDR-TH_6P-P2.54-V-M | | PZ254V-11-0 6P | XFCN(兴飞 ) | C492405 | LCSC
11 | 1 | 飞特总线进 | J4 | CONN-TH_B 3B-PH-K-S | | B3B-PH-K-S( LF)(SN) | JST | C131339 | LCSC
12 | 1 | 飞特总线出 | J5 | CONN-TH_B 3B-PH-K-S | | B3B-PH-K-S( LF)(SN) | JST | C131339 | LCSC
13 | 5 | 10k | R1,R2,R4,R5,R7 | R0603 | 10k | 0603WAF10 02T5E | UNI-ROYAL( 厚声 ) | C25804 | LCSC
14 | 1 | 33R | R3 | R0603 | 33R | 0603WAF33 0JT5E | UNI-ROYAL( ) 厚声 | C23140 | LCSC
15 | 1 | 150R | R6 | R0603 | 150R | 0603WAF15 00T5E | UNI-ROYAL( ) 厚声 | C22808 | LCSC
16 | 1 | STM32G031 F8P6 | U1 | TSSOP-20_L 6.5-W4.4-P0. 65-LS6.4-BL | | STM32G031 F8P6 | ST(意法半导 体) | C529334 | LCSC
17 | 1 | LSM6DSV16 XTR | U2 | LGA-14_L3.0 -W2.5-P0.50-BR | | LSM6DSV16 XTR | ST(意法半导 体) | C5267406 | LCSC
18 | 1 | SN74LVC2G 241DCUR | U3 | VSSOP-8_L2 .3-W2.0-P0.5 0-LS3.1-BR | | SN74LVC2G 241DCUR | TI(德州仪器 ) | C10430 | LCSC
19 | 1 | HT7533-1 | U4 | SOT-89-3_L4 .5-W2.5-P1.5 0-LS4.2-BR | | HT7533-1 | HOLTEK( 合 泰 /盛群 ) | C14289 | LCSC

20

1 | 16MHz | X1 | OSC-SMD_4 P-L3.2-W2.5- BL_SIT8008 BI
16MHz | S3D16.0000
00B20F30T

SCTF(星通时 频)

C387369 LCSC

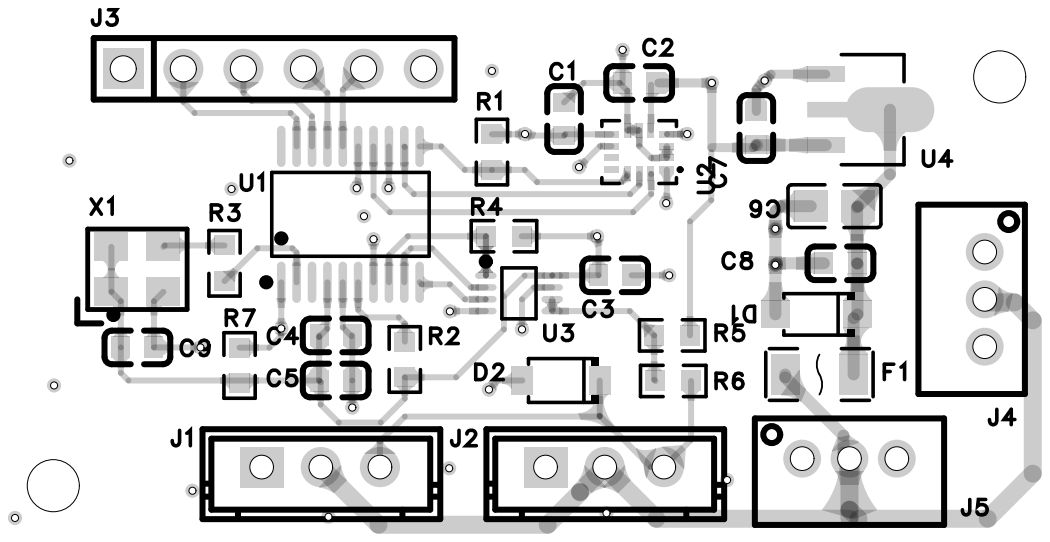
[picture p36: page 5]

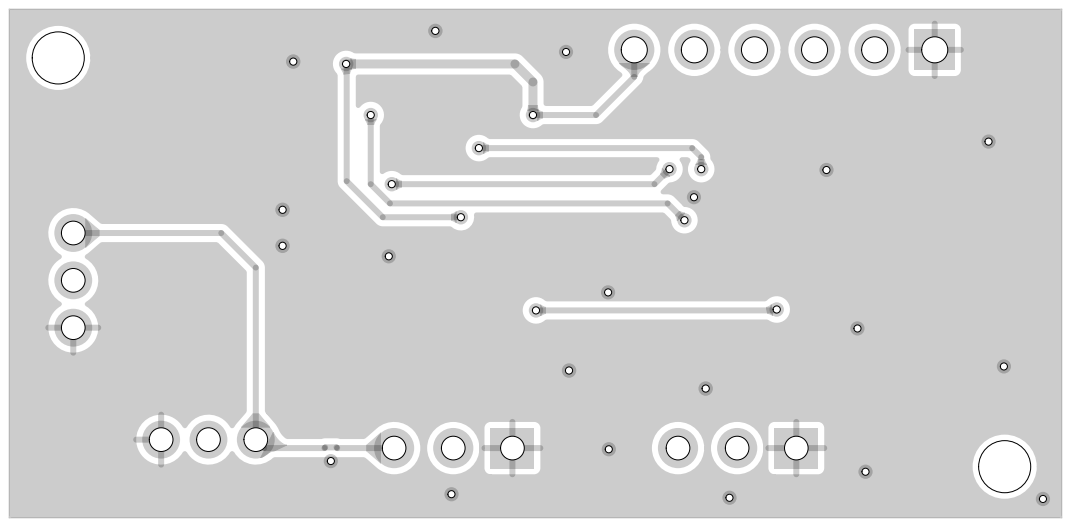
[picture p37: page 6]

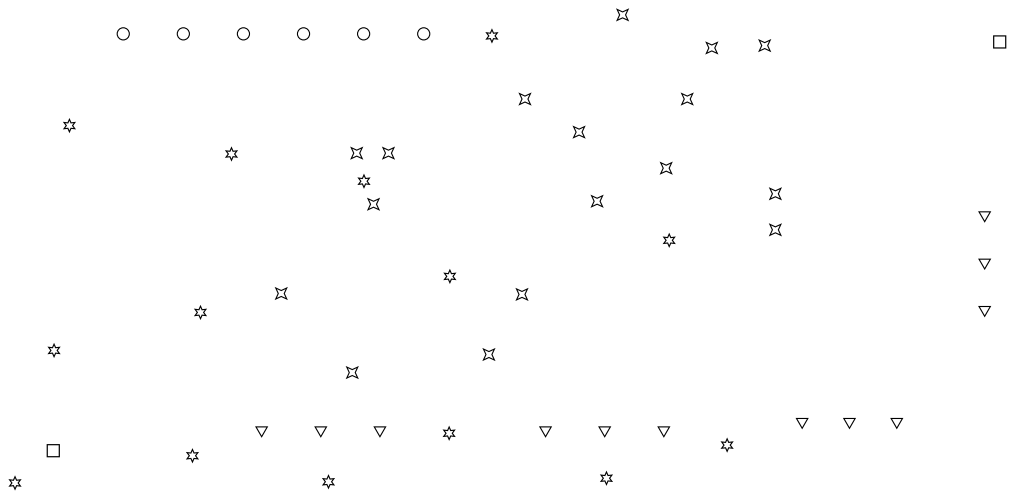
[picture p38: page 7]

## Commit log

2026-08-28 Microduck 复刻：从 MJCF 反推装配图与 CAD 装配体
    上游只发布了仿真模型，没有装配文档。本仓库把 MJCF 里的运动学树
    还原成人能看的装配图，并把 47 个零件坐标系的 STL 变换到世界坐标，
    导出可直接导入 CAD 的装配体。
    - assembly-drawings/ 7 张渲染图，含 2 张带标注的爆炸图
    - cad/ 15 个已装配部件 STL + 整机单文件（796792 三角面）
    - scripts/ 渲染与导出脚本，可完整重现
    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
    [01_躯干主体.stl, 02_左髋yaw-roll.stl, 03_左髋roll.stl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]
2026-08-28 反推紧固件清单与执行器选型
    孔特征扫描（scripts/analyze_holes.py）：焊接顶点建面片邻接图，按二面角
    切割出光滑曲面片，对每片拟合圆柱定出直径，法向朝向判别孔与凸台。
    47 个零件 2.5 秒扫完。
    结论：
    - 整机是 M2 螺丝系统 —— Ø2.2 过孔 x77 + Ø4.4 沉头孔 x28 + Ø1.6 攻丝底孔 x20
    Ø2.2 与 Ø4.4 成对出现，是 M2 内六角柱头的过孔+沉孔组合
    - 结构件过孔约 146 个，按孔深分布给出螺丝长度采购量
    - 轴承 Ø22x16x4 与 Ø15x10x3
    - 修正舵机数：xl330 网格整机引用 15 次，不是 14 个
    14 个受策略控制，第 15 个驱动喙/下颚走被动连杆
    执行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
2026-08-28 添加零安装 STL 查看器
    单文件 HTML + 原生 WebGL，无外部依赖。拖入 .stl 即可查看，
    显示三角面数与实际尺寸(mm)，左键旋转/右键平移/滚轮缩放。
    支持二进制与 ASCII 两种 STL 格式，适配浅色深色主题。
    用于在没装 CAD 的机器上快速查看 cad/ 下的装配体。
    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
2026-08-29 逆向出完整电控方案，修正「电控是硬墙」的结论
    思路：运行时要驱动真实硬件，就必须写死设备路径、I2C 地址、寄存器偏移、
    波特率和协议——代码即规格书。
    主要发现：
    - 主控是市售的 Radxa Zero 3W（设备树 compatible = "radxa,zero-3w"），
    不是定制载板。此前判断有误，已在 README 与 PROGRESS 中修正
    - 自制板一 imu_to_dxl v2：LSM6DSV16X 挂 Dynamixel 总线 ID 200，寄存器 124，
    12 字节块 = 陀螺 i16x3 (±500dps) + SFLP 四元数 fp16x3，w 由归一化反解。
    与 15 个舵机同一次 sync_read 读回
    - 自制板二 RPI Robot HAT：TLV320AIC3104@0x18 + BMI088@0x19/0x68（未使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
2026-08-29 补充通讯方案与主控选型依据
    - 主总线是单线半双工 TTL UART（Dynamixel Protocol V2 @ 1Mbps），
    不是 RS232 也不是 RS485：XL330 是 3-pin TTL，RS485 是 XM/XH 系列。
    全仓库搜 rs485/rs232/direction pin 零命中，方向切换由硬件自动方向电路完成
    - 记录 Armbian 默认在 UART2 跑 serial-getty 抢占串口的坑
    - 列出全部接口：UART2 / I2C3 / I2S3 / MIPI CSI / 蓝牙 / WiFi / USB-C
    - 说明为什么必须 Linux SoC 而非 MCU：WebRTC 硬编 + ONNX 推理 + NPU 检测
    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
2026-08-31 交叉验证官方规格，记录开源立场与社区动态
    官方 8/27 发布后公布了部分规格，与本仓库的逆向结果逐项对照：
    - 互相印证：RK3566、NP-F550、8x8 ToF、宽 140mm 全部对上
    - 官方补足了源码里没有的：RAM 1GB + 32GB eMMC（正是 Radxa Zero 3W 的
    一个 SKU，反向佐证了主控判断）、NPU 0.8 TOPS、NFC 双天线
    - 逆向独有的：主控型号、主总线方案、全部芯片 I2C 地址与总线协议
    - 发现矛盾：官方标 2 个 IMU，但源码里只有 LSM6DSV16X 在用，
    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
2026-08-31 补充外部验证：他人独立得出相同的主控结论
    X 上 @tspy 于 2026-08-31 发布的硬件拆解（169 赞）独立列出了 Radxa ZERO 3W /
    RK3566、15×XL330、NP-F550、8x8 ToF、50Hz 等，与本仓库逆向结论完全一致。
    两条独立路径得出同一答案。
    同时记录一个重要前提：截至 8/31 市面无实物（圣诞前发货），所以目前所有
    "teardown" 都是基于公开软件与规格的推理而非物理拆解；本仓库深入到 I2C 地址、
    寄存器布局与总线协议一层，来源是把 Rust 源码当规格书读。
    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
2026-08-31 归档社区情报，记录逆向结论的外部验证
    新增 docs/社区动态.md：
    - 时间线与热度数据（官方三推约 860 万浏览，GitHub 三天涨 3.7 倍）
    - 外部验证：X 上 @tspy 的硬件拆解独立得出 Radxa ZERO 3W / RK3566，
    与本仓库逆向结论完全一致；其成本判断("成本貌似比直接购买要高")亦一致
    - 列出本仓库相对社区公开分析的深度差（总线电气层、I2C 地址、
    IMU 数据块布局、装配几何、紧固件均为社区未覆盖）
    - 记录社区四天内做出的二次开发项目
    - 记录 GitHub 三个索要硬件文件的 issue 及官方零回复
    风险标注：
    - 区分可核实事实与二手传闻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
2026-08-31 添加英文 README，中文为首选
    awesome-microduck 收录本项目时特意标注了 "In Chinese"，说明语言是传播的
    实际门槛。现在两个版本互相链接，中文 README.md 保持首选，英文 README.en.md
    覆盖同样的内容深度——不是摘要，是完整对照版本。
    英文版同时补上了中文版之后才加的电控逆向部分：总线拓扑图、Radxa Zero 3W、
    imu_to_dxl 的 Dynamixel 从机设计、两块自制板、三个必踩的坑。
    仓库描述改为中英双语。
    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
2026-08-31 执行器选型：解释为什么是 XL330，以及换舵机的真实代价
    回答两个高频问题——为什么不用闭环步进，以及能不能不改机械件换成
    便宜五倍的飞特 STS3215。
    硬数据对照（同为 15 刚体的双足机器鸭，取自两边的 MJCF）：
    - 整机质量 XL330 版 737.2g vs STS3215 版 2107.1g，差 2.86 倍
    - 执行器参数 kp 差 32 倍、forcerange 3.5 倍、damping 与 frictionloss
    各 11 倍、armature 15.5 倍——每一项都差一个数量级
    - 反直觉：XL330 建模的回差反而更大（±1.0° vs ±0.5°）
    结论是没有中间路线：保 XL330 则机械件可直接用本仓库的 CAD、官方策略
    直接跑；换 STS3215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
2026-08-31 补充同级别舵机横向对比，说明那个空档为什么还没被填上
    新增一张五款舵机的横向对比表（XL330-M288/M077、飞特 STS3032/SCS0009/
    STS3215），列出重量、尺寸、堵转力矩、电压、编码器与减速比。
    关键发现：
    - 飞特 STS3032 尺寸比 XL330 还小（23.2x12.1x28.5 vs 29x20x34）、
    重量相当（20g vs 18g）、12-bit 编码器同级、半双工总线同架构，
    但力矩只有 46%（0.44 vs 0.96 N·m）且电压上限 6V，
    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
2026-08-31 深度评估宇树 S288：目前唯一全面对标 XL330 的产品
    通读官方《无刷数字舵机 J288/S288 使用手册》11 页，补进选型文档。
    机械上几乎是平替：19.5g（XL330 18g）、34x20x23mm（XL330 20x34x26mm）、
    减速比 288.35:1 与 XL330 完全相同、M2 固定螺丝、单线半双工 TTL 总线。
    连型号里的 288 都一样，看得出是刻意对标。
    两个实质升级：
    - 阻抗控制 τ = τ_ff + k_p(p_des-p) + k_d(ω_des-ω)，底层 FOC 闭环。
    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
2026-09-01 英文版硬件逆向文档
    翻译 docs/硬件方案逆向.md 为 docs/hardware-teardown.en.md（426 行），
    与中文版互相链接。
    为什么先翻这一份：awesome 列表收录本项目时特意标了 "In Chinese"，而流量
    数据显示 Google 仅 5 次、Bing 132 次——英文圈基本没进来。这份文档是站内
    访问第 2（84 次），更重要的是它是全网独有内容：HF 员工 @mishig25 的 3D
    解剖 Space（3.6 万浏览）已经把"整机长什么样"讲清楚了，规格类文档与其重合，
    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
2026-09-01 英文版执行器选型文档
    翻译 docs/执行器选型.md 为 docs/actuator-selection.en.md（459 行）。
    这份是全网独一份的内容：把 XL330、飞特 STS3215/STS3032/SCS0009、
    宇树 S288/J288 六款同级别舵机的重量、尺寸、力矩、电压、编码器、减速比
    横向摆在一起，并给出两个实测硬数据——同为 15 刚体双足鸭，XL330 版
    737.2g vs STS3215 版 2107.1g；执行器标定参数每一项差一个数量级。
    同时英文化了：为什么不能用闭环步进的四条理由（其中反驱性最关键）、
    宇树 S288 的深度评估（含力矩标注歧义与向厂商求证的四个问题）、
    以及"空档正在被挤压"的市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
2026-09-01 英文版紧固件反推文档，英文化告一段落
    翻译 docs/紧固件反推.md 为 docs/fastener-reconstruction.en.md（115 行）。
    至此三份核心技术文档全部双语：硬件方案逆向、执行器选型、紧固件反推，
    加上 README 共 4 份，均双向互链。
    硬件规格速查暂不翻——它与 HF 员工 @mishig25 的 3D 解剖 Space（3.6 万浏览）
    内容重合度高，英文读者那一层需求已被覆盖。社区动态与 PROGRESS 不翻，
    前者时效性强会过期，后者是内部进度记录。
    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
2026-09-01 新增构建日志：从纸上分析走向实物验证
    同事已开始 3D 打印首批零件，大致外形成型。这是本项目第一次有实物进展，
    也是全网第一次有人真正去验证"仿真 STL 能不能打印装配"这个问题。
    结构上单开 构建日志.md / BUILD-LOG.en.md 而不是塞进 README——README 讲
    "这个项目是什么"，日志讲"我们做到哪了"，两种读者、两种更新频率。
    README 顶部只加一个指向日志的小节，放在爆炸图之前。
    日志预留了四块：进度表、打印记录、踩过的坑（按现象-原因-解决写）、
    尺寸与配合验证（把反推值和实测值并排对照）。
    其中"尺寸验证"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
2026-09-01 首批实物照片：M2 螺丝装进去了
    头壳、躯干壳、腿部结构件和脚已打印完成，头颈已连接。头部是多色打印
    （白/黑/红），含摄像头环座与指示灯开口。
    关键在于黑色腿部件上的 M2 螺丝已经装入——这是本项目第一个实物验证点：
    docs/紧固件反推.md 靠扫描 47 个 STL 的孔特征得出"整机是 M2 螺丝系统"，
    现在在实物上成立了，至少这几个孔位是。
    精确孔径实测数据待补。README 顶部的实物进度块换成带照片的版本，
    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
2026-09-03 重要勘误：HAT 板官方其实已开源；补 NPU 章节与交流群
    此前全仓库写着「Microduck 硬件不开源、没有 BOM、没有 PCB 原理图」——
    这是错的。RPI Robot HAT 板在 pollen-robotics/elec_RPI_Robot_HAT 有完整
    开源工程（Apache-2.0）：KiCad 9 原理图与 PCB、Gerber、BOM、贴片坐标、
    STEP、以及全部器件手册。
    出错原因：当初只检索了 pollen-robotics/microduck 主仓，没有翻查该组织下
    以 elec_ 开头的硬件仓库。教训是判断「某项目有没有开源某部分」时必须检索
    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
2026-09-03 新增 print/：整机 46 个单件 STL，按打印件与标准件分类
    仓库此前只有 cad/ 里的 16 个装配体（用来看装配关系），缺最常被需要的
    东西——可以直接拿去打印的单件文件。
    print/ 收整机全部 STL，两级分类：
    - 打印件/ 37 个需要自己打印的结构件
    - 标准件-无需打印/ 9 个外购件模型（舵机、轴承、电池、两块 PCB 等），
    仅供对位与干涉检查
    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
    [ankle_l_v1_脚踝左V1.stl, ankle_left_脚踝左.stl, ankle_r_v1_脚踝右V1.stl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]
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2026-09-03 新增整机 BOM；修正 XL330 电压口径与电池型号；print/ 按装配体重组
    外部评审（Fable 5.1）指出三处会让人做错事的问题，本次一并修正，并补上
    仓库一直缺的整机物料清单。
    一、XL330 不是 7.4V 舵机 —— 核心结论建在错误前提上
    Robotis 官方规格：输入 3.7–6.0V，推荐 5V，堵转 0.52 N·m @5V。
    而 Microduck 给舵机 6.6–8.2V（BAM vin_range、robotd 电压钳位、2S 电池三处印证）。
    也就是 Pollen 在超压运行 XL330，这个事实此前一个字都没写。
    它连带推翻两处：
    - 否决飞特 STS3032 的理由是「电压上限 6V 会烧」，但 XL330 上限同样是 6V，
    区别只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
    [ankle_l_v1_脚踝左V1.stl, ankle_r_v1_脚踝右V1.stl, rim_轮辋.stl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]
2026-09-03 BOM 核数修正：删掉漏删的重复件，更正件数、价格、板宽、孔数与输入电容耐压
    外部核数（Fable 5.1，逐条回一手来源）查出一个真错误和若干口径问题。
    ❌ 打印件件数错了，根因是我上一次删除操作静默失败
    right_upper_leg_右上腿.stl 与 upper_leg_right_右上腿.stl 是同一几何体的两次
    导出（12250 面、包围盒、质心完全一致），任何 MJCF 都不引用，上游 8dfc08f 已删。
    上次用 rm -f 删的是一个从未存在的路径（该文件没被移进 上游已删除/），
    而 rm -f 对不存在的文件不报错，于是文档写了「已删除」实际还在。
    现已真正删除，件数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
    [right_upper_leg_右上腿.stl]
2026-09-03 中英文 README 对齐；补全许可证覆盖范围；统一舵机价格口径
    一、中英文对等（仓库自定标准，此前差距最大的一处）
    中文 README 此前缺了两个英文版独有的章节，而其中第一个恰恰是本仓库最独特的
    内容：
    - 新增「从运行时反推出的电控方案」：系统框图 + 主控/总线/两块自制板/电池/
    传感器总表，以及 imu_to_dxl 把 IMU 伪装成 Dynamixel 从机的设计说明
    - 新增「三个必踩的坑」：UART2 上的 getty、i2c3 与 FUSB302 抢引脚、NPU 默认关闭
    反向把中文独有的「结论已从『机械可抄、电控是硬墙』修正为『整机可复刻』」
    补进英文版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
2026-09-04 审核勘误：bearing_roll 分类、板卡配置、MK1 型号、质心量级与电源树
    一轮逐条对照源文件的审核，改掉七处经不起查证的说法。
    bearing_roll 是打印件，不是采购的轴承
    - 实测 23×3×40mm、带 Ø≈18 中心孔的平板（体积 625mm³），不是回转体；
    两颗真轴承实测 22.0/16.0/4.0 与 15.0/10.0/3.0
    - assets/*.part 的 Onshape elementId 显示它与 trunk_base、yaw2roll、外壳
    同属一个自建件 Part Studio，而真轴承在另一个带配置串的标准件库里
    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
    [bearing_roll_横滚轴承压盖.stl]
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2026-09-04 一轮审核勘误：摄像头角度、飞特协议论证、板卡口径，并收敛重复陈述
    上一轮勘误只改了"发起地"那一份，散在别处的四到六份副本没跟着动，仓库里
    一度同时存在两套互相打脸的说法。这次一并收齐，并补上导致这种漂移的结构问题。
    事实冲突裁定
    - 摄像头是转 90° 不是倒装 180°（mediad/src/main.rs:82 的 --rotate 默认 90，
    注释「the head camera is mounted a quarter turn off」）；media-bringup.md:472
    的 180° 是 alpha 机数据。此前 7 处两派并存，其中 BOM.md 拒绝下判断
    - 打印件计数统一为 30 种 / 41 件、标准件 8（bearing_roll 改判后的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
2026-09-05 放出 imu_to_dxl 原理图求评审；接口与去耦按官方手册修正
    官方唯一没开源的那块板，第三方复刻版画完了。未打样、未经实物验证，
    先放出来让人挑毛病。
    新增 hardware/imu_to_dxl/
    - imu_to_dxl-原理图.pdf / .png —— 22 个器件，STM32G031F8P6 + LSM6DSV16X
    + SN74LVC2G241 半双工缓冲，作为第 16 个设备挂舵机总线
    - imu_to_dxl-接线表.md —— 逐网络列出每个引脚，可直接对着核
    - imu_to_dxl.eprj2 —— 嘉立创 EDA 专业版工程，别人能直接打开改
    - README.md —— 设计说明 + 五个想听意见的点
    连通性已用脚本逐网络核对：89 个引脚、67 根导线、31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
2026-09-05 补全 .gitattributes 的二进制声明，避免 Windows 上 clone 损坏文件
    此前只声明了 *.stl 和 *.png，而 *.pdf / *.jpg / *.eprj2 / *.STEP / *.zip
    全部未声明。在 core.autocrlf=true 的 Windows 上，git 会对它判定为文本的
    文件做 LF→CRLF 转换 —— clone 下来的 PDF 和工程文件直接损坏。
    git 的自动二进制探测靠采样文件头有无 NUL 字节，对 PDF 这类头部多为 ASCII
    的格式会误判。提交 imu_to_dxl 原理图时 git 就给出了
    "LF will be replaced by CRLF" 警告，说明确实被当成了文本。
    受影响的已有文件：assets/hw/Microduck硬件图集.pdf、
    build-log/photos/*.jpg 与本次新增的原理图 P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
2026-09-05 README 首屏改版：二维码下面加「最近更新」，电气与机械并排
    此前原理图单独占一节、实物进度另占一节，首屏很长，而且两条线的进展
    被切成上下两块，看不出「电气和机械在同时推进」。
    改为二维码正下方一个双列表格：
    - 左列 电气 —— imu_to_dxl 原理图（图 + 一句话 + 四个入口）
    - 右列 机械 —— 首批打印件（图 + 一句话 + 三个入口）
    两张图都可点击，分别进设计说明和构建日志。
    评审征集从正文提为表格下方的引用块，三条问题保留。
    实物进度一节去掉已上移的照片与正文，只留「STL 不是制造文件」那句立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
2026-09-06 imu_to_dxl 从原理图做到 PCB：45×22 双层板，底层整片地
    原理图之后把板子布完了。45 × 22 mm，2 层，1 oz 铜，四角 R2 圆角，
    两个对角 M2 非金属化孔。贴片件全在正面，DRC 0 违规，未打样。
    板框走 DXF，不是画的
    立创专业版这一版的图元接口只接受铜层。往板框层（layer 11）建线/弧一律
    报「参数不正确」；换参数形态、换图元类型（Polyline / Fill / Region /
    String）、解锁该层、把 ACTIVE_LAYER 切过去、先在铜层建好再 modify 改层、
    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
    [imu_to_dxl-PCB.step, imu_to_dxl-板框-45x22-R2.dxf]
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2026-09-08 修掉两个指向仓库外的死链；J4/J5 措辞改准确
    上一个提交引入的问题，自查链接时发现。
    一、两处链接指到了仓库外面
    docs/硬件方案逆向.md ../../hardware/参考手册/
    hardware/imu_to_dxl/README.md ../../../hardware/参考手册/
    那个目录在本地工作区（Microduck/hardware/参考手册/），不在仓库里，
    相对路径会跳出仓库根 —— GitHub 上必定 404。
    改成纯文本引用，跟仓库既有惯例一致：NOTICE.md 写明「不重复托管上游代码」，
    全库引手册都是只给文档号加页码（DS12992 Rev 3, Table 12 / ST DS13510 Rev 1 /
    飞特官方《舵机SCS通信协议》），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
2026-09-08 更新 .eprj2 到含 J4/J5 的最终版；PDF 与 STEP 仍待重导
    工程文件
    2,387,968 → 2,646,016 字节（+258 KB），导出时间 2026-09-08 20:37 ——
    在 J4/J5 布线完成、以及删掉 J2.3 上那个重合过孔并保存之后。体积增长与
    「多两个器件 + 更多走线」吻合。
    ⚠️ 内容未做逐字节验证：.eprj2 是 SQLite，文档正文以本仓库脚本未能识别的
    格式存储（对已知含 R7/X1 的旧版做同样解析也是零命中，说明是解析方法的问题
    而非文件的问题）。这里的依据是导出时间与体积，不是内容比对。
    仍未更新的三个
    imu_to_dxl-PCB.pdf 09-07
    imu_to_dxl-原理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
2026-09-08 刷新 PCB / 原理图 PDF、STEP 与原理图 PNG 到含 J4/J5 的最终版
    至此本目录与 assets/ 下的全部文件都是 2026-09-08 的最新状态，不再有
    「工程是新的、图纸是旧的」这种混合状态。
    导出内容已核对，不是只看时间戳
    PCB PDF 7 页，文本里 J1–J5 / R7 / X1 / B3B-PH-K-S /「飞特」齐全
    原理图 PDF 1 页，J1–J5 / R7 / X1 / RX_EN / DXL_BUS 齐全，更新日期 2026-09-08
    原理图 PNG 由新的原理图 PDF 以 2400 px 宽重新渲染（旧图是 09-06 的）
    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
    [imu_to_dxl-PCB.step]
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2026-09-24 链接 HD1910 训练分支与模型初始化修复说明
2026-09-24 Consolidate HD1910 training in replica repository
    Include the fixed training source, models, borrowed M6 parameters, initialization adapter and tests under software/training. Route setup and attribution docs to this repository and make HF source archives work from a nested training project.
    Validated: fresh locked WSL install, 26 integration/regression tests, 4 offline packaging tests and 64-env/5-iteration PPO smoke run. Parameter bytes and unchanged source blobs match the fixed origin.
    [ankle_l_v1.stl, ankle_left.stl, ankle_r_v1.stl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]
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2026-11-02 docs: track duck-sim gait and backlash proposal
2026-11-02 docs: track merged simulator fix and distinct pairing development contracts
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2026-11-03 docs: record stress guard reversal and look-back prototype
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2026-11-04 docs: track five pending upstream validation fixes
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2026-11-04 fix(studio): allow held HOME sampling during IMU recalibration
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2026-11-04 fix(studio): collect IMU mounting calibration while holding motion HOME
2026-11-04 docs: record published HOME calibration fix and device preflight
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2026-11-04 fix(studio): require independent IMU verification proof
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2026-11-04 fix(studio): pin control.48 and preserve paired update recovery
    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
2026-11-05 docs: track merged roller fixes and audio recording proposal
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2026-11-05 docs: track WebRTC session update gate and roller height fix
2026-11-05 docs: track Spaces HTTP control reply framing fix
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2026-11-09 feat: add phone voice bridge and expanded board voice control
    Expand duck-echo recognised commands (walk/stop, skills, chirp/greet, head
    gestures) with multi-command parsing, report the last command and its failure
    reason to clients, and auto-start the walking policy once upright. Add HTTPS
    support plus a phone_bridge module so phones can use their own microphone for
    on-board ASR and keep camera signalling working over TLS.
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2026-11-09 fix: confirm walking policy actually starts after robot.enable
    robot.enable only acknowledges the request: fork robotd starts the policy
    in its control loop and may keep refusing it (home_start_guard) until the
    pose and servo feedback settle. Studio's "start walking" used to log a
    success on the ack alone.
    Read back busStatus.policy_enabled within a short window after the ack;
    if the policy never starts, surface robotd's own reason
    (last_enable_refusal / home_start_guard.reason) instead of a false
    success. duck-echo's automatic policy start retries transient refusals in
    a window and reports the real reason too. Head actions on the phone now
    ensure the policy is running before feeding the ob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
2026-11-10 docs: track lower gamepad reverse default
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
